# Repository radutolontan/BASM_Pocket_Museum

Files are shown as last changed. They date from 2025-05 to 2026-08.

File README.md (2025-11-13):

# Introduction

The Pocket Lab is the next-generation approach to science education. Designed by the Bucharest Applied STEAM Museum, it brings scientific exploration into anyone's hands. From citizen science projects to fearless exploration (guided or individual), the Pocket Lab illuminates the connections between Science, Technology, Engineering, Art, and Math in the world around us.

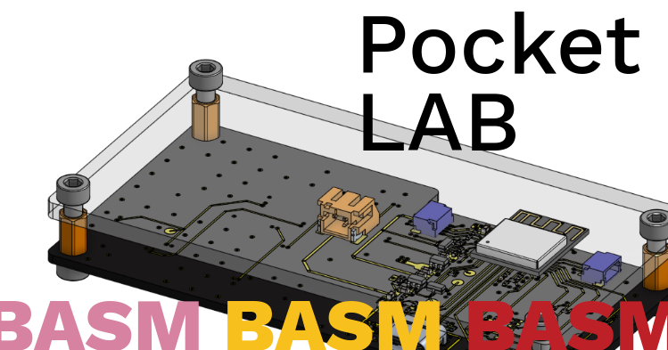
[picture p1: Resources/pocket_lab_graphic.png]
Graphic


---

# Hardware Design

The system is built around an **ESP32-C6 MINI** microcontroller, which offers:
- Powerful processing capabilities
- WiFi and Bluetooth connectivity
- Excellent integration with accessible codebases through Arduino

The microcontroller collects data from a suite of sensors (9-DOF IMU, light, pressure, audio) and uses a chain of WS2812B RGB LEDs to relay measurements to the user. An on-board microSD card enables data logging and automated grading of student work. Everything is powered by a 3.7V LiPo cell, which is charged using the USB-C connector.
## Board ID - Education V0
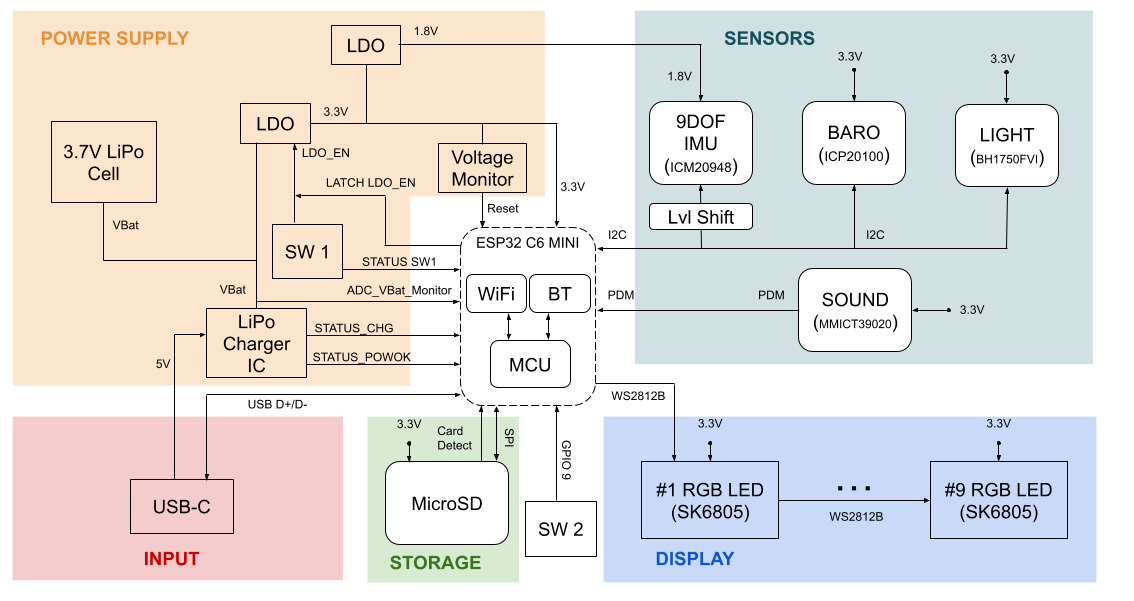
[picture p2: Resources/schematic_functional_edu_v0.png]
diagram_HW


### Power
The power stage is designed for a **500 mAh, 3.7V LiPo cell**. Key specifications:
- **Charger IC**: Configured to supply 450 mA in constant-current regime; stops charging when current drops below 150 mA in constant-voltage regime
- **USB-C Power**: Non-negotiated supply limited to 5V @ 500 mA (sufficient for system operation)
- **Voltage Monitor**: Prevents brown-out behavior on the ESP32 when the 3.3V rail drops below 2.9V
- **Power Latching**: A simple circuit enables and latches the LDO through push-button SW1 and an ESP32 GPIO 

### Display
The display consists of a chain of NeoPixel RGB LEDs organized across three zones:

**Mode Display (2 LEDs)** - Color-coded indication of the actively displayed quantity:
- WHITE → Light
- MAGENTA → Sound
- YELLOW → Magnetic Field
- GREEN → Acceleration
- ORANGE → Gyroscope
- RED → Air Temperature
- BLUE → Air Pressure

Additional device information is also displayed (e.g., battery state: Blinking Orange = Battery Low; Blinking Green = Charging; Blinking Blue = Fully Charged)

**Magnitude Display (3-4 LEDs)** - Conveys scalar quantities and magnitudes of vector quantities

**Direction Display (3 LEDs)** - Conveys qualitative Cartesian components (X, Y, Z) for vector quantities
- *Note: Direction Display is only available in Binary Display Mode (see Software Architecture section)*

### Sensors
The Pocket Lab EDU V0 includes the following sensors:

| Sensor | Measurements |
|---|---|
| **ICM-20948** | 9-DOF IMU: translational acceleration, rotational velocity, magnetic field strength |
| **ICP-20100** | Ambient temperature and air pressure |
| **BH1750FVI** | Ambient light intensity |
| **MMICT390200012** | Microphone: sound pressure level (dB) |

### Programming
The MCU can be programmed through **Joint Download Boot Mode**:

1. Connect the Pocket Lab to a host computer using a USB-C data cable
2. Hold down **SW2** (labeled "MOD"; connected to GPIO 9)
3. While holding SW2, press and hold **SW1** (labeled "ON/OFF")
4. Release SW2 while keeping SW1 pressed
5. Release SW1

The USB-serial connection appears as `/dev/ttyACM*` (Linux) and allows PlatformIO to flash code to the ESP32-C6.

# Software Architecture

The software architecture is built around a FreeRTOS task-based design with a central `shared_data_buffer` for inter-task communication. Tasks are organized into two tiers:

## Task Organization

### First-Tier Tasks (Core System)
These tasks are **always active** and form the foundation of the Pocket Lab operation:
- **BMSTask** - Battery management and power control
- **SensorTask** - Sensor data acquisition and processing
- **AudioTask** - Audio input/output management
- **DisplayTask** - User interface via NeoPixel LEDs

### Application-Level Tasks (Feature-Specific)
These tasks are **conditionally enabled** based on active applications, demos, or features:
- **SDManager** - MicroSD card operations for data logging
- **EvaluatorTask** - Student performance assessment and grading
- **NetworkTask** - WiFi/Bluetooth connectivity features

## System Architecture Diagram

```mermaid
graph TB
    subgraph "First-Tier Tasks"
        BMS[BMSTask<br/>Power Management]
        SENSOR[SensorTask<br/>Data Acquisition]
        AUDIO[AudioTask<br/>Audio I/O]
        DISPLAY[DisplayTask<br/>Visual Feedback]
    end

    subgraph "Shared Memory"
        BUFFER[(SharedBuffer<br/>Circular Buffer)]
    end

    subgraph "Application Tasks"
        SD[SDManager]
        EVAL[EvaluatorTask]
        NET[NetworkTask]
    end

    BMS -->|Power Status| BUFFER
    SENSOR -->|Sensor Data| BUFFER
    AUDIO -->|Audio Data| BUFFER

    BUFFER -->|Latest Data| DISPLAY
    BUFFER -->|Historical Data| SD
    BUFFER -->|Statistics| EVAL
    BUFFER -->|Stream Data| NET

    BMS -.->|Shutdown Signal| SENSOR
    BMS -.->|Shutdown Signal| AUDIO
    BMS -.->|Shutdown Signal| DISPLAY

    DISPLAY -->|Mode Changes| BUFFER

    style BMS fill:#ffcccc
    style SENSOR fill:#ccffcc
    style AUDIO fill:#ccccff
    style DISPLAY fill:#ffffcc
    style BUFFER fill:#ffccff
```

## Detailed Task Descriptions
### 1. SensorTask
Responsible for initializing, managing, collecting, and processing sensor data. Pushes each new raw reading to the `shared_data_buffer`. Uses the **SensorHAL** virtual layer, as implemented in `specific_sensor_HAL`, to standardize high-level I/O across all sensors.

Furthermore, note that different sensors are sampled at different rates based on their response characteristics and application requirements.
The task maintains individual timers for each sensor and only reads when that sensor's interval has elapsed, optimizing power consumption and computational load.

#### States
* **BOOT** - Default state on boot-up; transition to INIT triggered from main.cpp
* **INIT** - Initializes I2C bus for communications to sensors, configures and confirms communications with all sensors
* **READ** - If a sensor is ready to read (based on its individual `read_rate_Hz`), captures a raw reading and commits it to the latest frame of `shared_data_buffer`

### 2. BMSTask
Responsible for managing power delivery to the Pocket Lab. Monitors battery health, informs user about remaining run-time, and handles power-up and shut-down of the entire system.

#### States
* **BOOT** - Waits until startup timer expires. Prevents accidental power-up if SW 1 is bumped.
* **STARTUP_LATCH** - Configures Charger IC monitoring pins after confirming power is latched.
* **ACTIVE** - Monitors feedback from the Charger IC & Battery Voltage predictions to infer ChargeControllerState:
    * **BATTERY_ONLY** - Charger unplugged & battery supplying power
    * **LOW_BATTERY** - Charger unplugged & battery supplying power & less than 30 minutes of battery life remaining
    * **CHARGING** - Charger connected & battery charging
    * **DONE_CHARGING** - Charger connected & supplying power to system (battery charging complete)
* **SHUTDOWN_PENDING** - When SW 1 is pressed to initiate a shut-down, the LDO is un-latched and other tasks are informed to facilitate a clean shut-down.

#### ⚠️ Known Critical Issues
The current BMSTask implementation has several critical issues that will be addressed in future revisions:
- **Limited voltage monitoring**: VBat is only checked when in `BATTERY_ONLY` state, missing voltage drops during charging or when connected to USB
- **No automatic low-voltage disconnect**: The system does not automatically disconnect power when VBat drops dangerously low, risking deep discharge that could trigger the battery's undervoltage lockout protection

### 3. AudioTask
Manages audio input and output operations for the Pocket Lab. The AudioTask is responsible for interfacing with the microphone sensor (MMICT390200012) and any future audio peripherals through a Hardware Abstraction Layer (HAL).
This decouples high-level audio processing from hardware-specific implementations, allowing to scale audio I/O in the future.
Like the SensorTask, the AudioTask writes processed audio data (e.g., sound pressure level in dB, frequency analysis) to the `shared_data_buffer`.

#### States
* **BOOT** - Default state on boot-up; transition to INIT triggered from main.cpp
* **INIT** - Initializes audio peripherals through the AudioHAL, configures sampling parameters
* **SAMPLING** - Actively captures audio data at the configured sample rate, processes it, and commits results to `shared_data_buffer`
* **IDLE** - Audio acquisition paused (e.g., during low-power modes or when no audio display is active)

### 4. DisplayTask
Manages the primary user feedback tool, the chain of NeoPixels. A push-button (SW 2 - display mode button) is debounced and used to cycle through DisplayStates. The current DisplayState is color-coded into the **Mode Display**.

#### States
* **BOOT** - Default state on boot-up; transition to INIT triggered from main.cpp
* **INIT** - Initializes the RGB LED strip and displays a color code for the GIT SHA (used to confirm proper code version is running)
* **DISPLAY_XX** - Pulls the latest value for the XX quantity from `shared_data_buffer`. Updates the **Magnitude Display** and **Mode Display** to reflect the measurement.

The DisplayTask supports two distinct visualization modes selected at boot time by holding (or not holding) the display mode button:

#### Visualization Modes - VU

VU mode provides a classic "volume unit" meter visualization reminiscent of analog audio equipment. In this mode, scalar measurements are displayed as a horizontal bar graph using 6 magnitude LEDs. The display shows the normalized percentage of the measurement relative to predefined min/max thresholds for each sensor type.

The magnitude LEDs use a gradient color scheme that transitions smoothly from green (low values) through yellow (mid-range) to red (high values), providing an intuitive visual indication of intensity. The more LEDs that are lit, the closer the measurement is to its maximum threshold. Vector quantities in VU mode display only their magnitude - no directional information is shown.

#### Visualization Modes - Binary (Integer Encoding)

Binary mode takes a fundamentally different approach by encoding the actual integer value of measurements rather than showing a percentage. This mode provides precise numerical information that can be decoded by reading the LED colors, making it particularly useful for debugging and data verification.

The system uses 4 magnitude LEDs to encode 12-bit values (0-4095) using a novel 3-bit-per-LED color encoding scheme:

**How Binary Encoding Works:**

Each RGB LED encodes 3 bits of information using its individual color channels:
- Blue channel = Bit m (LSB for that LED)
- Yellow channel = Bit m+1 (middle bit)
- Red channel = Bit m+2 (MSB for that LED)

The LEDs are arranged from left to right, with LED #1 (leftmost) showing bits 0-2, LED #2 showing bits 3-5, LED #3 showing bits 6-8, and LED #4 (rightmost) showing bits 9-11. This arrangement means that more LEDs being lit indicates a larger magnitude.

**Color Combinations:** The 3 bits per LED create 8 possible states (0-7), each displayed as a distinct color:
- `000` → OFF
- `001` → BLUE (bit 0 only)
- `010` → YELLOW (bit 1 only)
- `011` → GREEN (bits 0+1: blue+yellow = green)
- `100` → RED (bit 2 only)
- `101` → PURPLE (bits 0+2: blue+red = purple)
- `110` → ORANGE (bits 1+2: yellow+red = orange)
- `111` → WHITE (all three bits active)

**Example:** To encode the value 1059:
- 1059 in binary = `0100 0010 0011` = 2⁰ + 2¹ + 2⁵ + 2¹⁰
- LED #1 (bits 0-2 = `011`): Blue + Yellow = **GREEN**
- LED #2 (bits 3-5 = `100`): Red only = **RED**
- LED #3 (bits 6-8 = `000`): All off = **OFF**
- LED #4 (bits 9-11 = `100`): Red only = **RED**

Before encoding, sensor readings are multiplied by sensor-specific scaling factors (defined as `BINARY_MAG_ORDER_*` constants) to convert floating-point measurements into integer values. For example, temperature is multiplied by 10, so 25.3°C becomes 253, while pressure is multiplied by 10, converting 101.32 kPa to 1013 (then clamped to 4095). Note that acceleration and gyro measurements are very noisy and flicker significantly; the first two bits are masked, effectively rounding every measurement to a multiple of 4.

**Direction Display:**

Binary mode also displays vector components (X, Y, Z) using 3 dedicated direction LEDs. Each LED shows its component using a color gradient:
- **RED** → Negative values
- **OFF** → Near-zero values (±5% dead zone)
- **GREEN** → Positive values

The intensity of the color fades proportionally with the component's magnitude, providing both sign and strength information. 

## Application-Level Task Details

### 5. EvaluatorTask
Responsible for gauging user effort and measuring learning outcomes. The EvaluatorTask owns multiple instances of the abstract base class `EvaluatorBase`.

`EvaluatorBase` standardizes I/O across all evaluators, such as `DisplaySessionEvaluator` (which captures aggregate statistics on sensor data while a specific DisplayTask mode is active). This enables automated grading and feedback for educational activities.

#### States
* **BOOT** - Default state on boot-up; transition to INIT triggered from main.cpp
* **INIT** - Initializes and confirms appropriate logging is set up for all evaluators
* **RUNNING** - Checks progress on all evaluators and manages access to the SDManager queue for data logging
* **ERROR** - Error handling (not yet implemented)

### 6. SDManager
Owns operation of the microSD card. It manages access to the storage resource using a separate state machine, handling concurrent read/write requests from multiple tasks.

#### States
* **BOOT** - Default state on boot-up; transitions to INIT automatically after initializing SD queue
* **WAIT_FOR_INSERT** - Checks and debounces the state of the SD card detect GPIO
* **MOUNTING** - Starts SPI communications, mounts the SD card, and checks SD card metadata
* **READY** - Allows fulfillment of read/write requests in the queue
* **UNMOUNTING** - Unmounts the SD card if removal is detected
* **ERROR** - Error handling (not yet implemented)

### 7. NetworkTask
Manages WiFi and Bluetooth connectivity features. This task is enabled when network-based applications are active (e.g., data streaming, remote monitoring, firmware updates).

*Note: Full NetworkTask implementation details are under development.*

---

# SD Card Formatting

In order to read and write to the SD card, it must be formatted to **FAT32** with an **MBR** partition table.

## Formatting Instructions (Linux)

1. Insert the microSD card into a compatible card reader, connect to a Linux machine, and locate the device:
```bash
lsblk
```

2. Unmount any existing partitions and clear the card (replace `/dev/sdX` with your device):
```bash
sudo umount /dev/sdX*
sudo wipefs --all /dev/sdX
sudo fdisk /dev/sdX
```

3. Within `fdisk`, configure the following:
   - Press **`o`** → Create a new DOS (MBR) partition table
   - Press **`n`** → Create a new primary partition
   - Accept all defaults (press Enter)
   - Press **`t`**, then type **`c`** → Change partition type to W95 FAT32 (LBA)
   - Press **`w`** → Write changes and exit

4. Format the partition to FAT32:
```bash
sudo mkfs.vfat -F 32 -n SDCARD /dev/sdX1
```

The SD card is now ready for use with the Pocket Lab.

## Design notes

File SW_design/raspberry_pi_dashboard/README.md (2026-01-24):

# BASM Pocket Museum Dashboard

A web-based dashboard for the Raspberry Pi that receives sensor data from ESP32 "Pocket Lab" devices and provides real-time visualization, student notebooks, and user management.

## Features

### 1. Welcome Tab
- First-time user registration (name, grade, science interest)
- Returning user greeting ("Welcome back, [Name]!")
- MAC address-based identification (hashed for privacy)

### 2. Pocket Lab Data Tab
- Real-time display of active ESP32 devices
- Interactive sensor selection (checkboxes for each sensor)
- Flexible display modes: stripchart, numeric, both, or none
- Supports all sensors:
  - Temperature & Pressure
  - Ambient Light
  - Accelerometer (X, Y, Z, Norm)
  - Gyroscope (X, Y, Z, Norm)
  - Magnetometer (X, Y, Z, Norm)
  - Volume (RMS)
  - Spectral sensor (14 channels)

### 3. Pocket Lab Notebook Tab
- Teacher-published questions (multiple choice or free text)
- Student answer submission (one answer per question)
- Answer history tracking

## Architecture

- **Backend**: Python Flask + Flask-SocketIO
- **Database**: SQLite (lightweight, perfect for Raspberry Pi)
- **Communication**: UDP (port 5000) for ESP32 data, WebSocket for real-time browser updates
- **Frontend**: HTML/CSS/JavaScript (will be implemented next)

## Installation

### Prerequisites

- Raspberry Pi 4 (2GB+ RAM recommended)
- Raspberry Pi OS (Debian-based)
- Python 3.9+
- Static IP configured: 192.168.10.2

### Step 1: Clone Repository

```bash
cd /home/pi/
git clone <repository-url> BASM_Pocket_Museum
cd BASM_Pocket_Museum/SW_design/raspberry_pi_dashboard
```

### Step 2: Install Dependencies

```bash
pip3 install -r requirements.txt
```

### Step 3: Configure Environment

```bash
cp .env.example .env
nano .env
```

Edit `.env` to customize settings (or use defaults):

```env
FLASK_ENV=production
SECRET_KEY=<generate-random-secret-key>
UDP_PORT=5000
WEB_PORT=8080
ACTIVITY_TIMEOUT_SECONDS=5
SENSOR_DATA_RETENTION_HOURS=24
```

### Step 4: Initialize Database

```bash
python3 init_db.py
```

You should see:
```
✓ Database initialized successfully!
✓ Schema version 1 applied
```

### Step 5: Run the Application

For development:
```bash
python3 app.py
```

For production (systemd service):
```bash
sudo cp dashboard.service /etc/systemd/system/
sudo systemctl daemon-reload
sudo systemctl enable dashboard
sudo systemctl start dashboard
```

Check status:
```bash
sudo systemctl status dashboard
```

View logs:
```bash
sudo journalctl -u dashboard -f
```

## Configuration

### Network Setup

The Raspberry Pi must have a static IP address that matches the ESP32 configuration:

**Raspberry Pi**: 192.168.10.2
**ESP32 Devices**: 192.168.10.11, 192.168.10.12, etc.

Edit `/etc/dhcpcd.conf`:
```
interface eth0
static ip_address=192.168.10.2/24
static routers=192.168.10.1
static domain_name_servers=8.8.8.8
```

Restart networking:
```bash
sudo systemctl restart dhcpcd
```

### Firewall

Allow incoming UDP on port 5000 and HTTP on port 8080:

```bash
sudo ufw allow 5000/udp
sudo ufw allow 8080/tcp
```

## API Documentation

### REST API Endpoints

#### Users

**Register/Login User**
```http
POST /api/users/register
Content-Type: application/json

{
  "mac_address": "AA:BB:CC:DD:EE:FF",
  "name": "John Doe",
  "grade": "10th",
  "science_interest": "Physics and robotics"
}
```

**Get User**
```http
GET /api/users/<mac_id>
```

#### Devices

**Get Active Devices**
```http
GET /api/devices
```

**Get Specific Device**
```http
GET /api/devices/<node_id>
```

#### Sensor Data

**Get Sensor Data**
```http
GET /api/sensor-data/<node_id>?limit=1000&hours=1&sensors=temperature,pressure
```

Parameters:
- `limit`: Max records (default: 1000)
- `hours`: Data from last N hours (default: 1)
- `sensors`: Comma-separated sensor list (optional)

#### Questions

**Get Active Questions**
```http
GET /api/questions
```

**Create Question (Teacher)**
```http
POST /api/questions
Content-Type: application/json

{
  "question_text": "What is the acceleration due to gravity?",
  "question_type": "multiple_choice",
  "options": ["9.8 m/s²", "10 m/s²", "8.9 m/s²", "11.2 m/s²"],
  "created_by": "Mrs. Smith"
}
```

**Delete Question**
```http
DELETE /api/questions/<question_id>
```

#### Answers

**Submit Answer**
```http
POST /api/answers
Content-Type: application/json

{
  "question_id": 1,
  "mac_id": "<hashed_mac_id>",
  "answer": "9.8 m/s²"
}
```

**Get User Answers**
```http
GET /api/answers/user/<mac_id>
```

**Get Question Answers (Teacher)**
```http
GET /api/answers/question/<question_id>
```

#### Preferences

**Get Preferences**
```http
GET /api/preferences?mac_id=<mac_id>&node_id=<node_id>
```

**Save Preferences**
```http
POST /api/preferences
Content-Type: application/json

{
  "mac_id": "<mac_id>",
  "node_id": "LAB_01",
  "sensor_type": "temperature",
  "display_type": "both"
}
```

Display types: `stripchart`, `numeric`, `both`, `none`

### WebSocket Events

**Connect**
```javascript
const socket = io('http://192.168.10.2:8080');
```

**Subscribe to Device**
```javascript
socket.emit('subscribe_device', {node_id: 'LAB_01'});
```

**Receive Sensor Data**
```javascript
socket.on('sensor_data', (data) => {
  console.log(data.node_id, data.data);
});
```

**Receive New Question**
```javascript
socket.on('new_question', (question) => {
  console.log('New question:', question);
});
```

## Maintenance

### Automatic Cleanup

Add to crontab for hourly cleanup:

```bash
crontab -e
```

Add line:
```
0 * * * * /usr/bin/python3 /home/pi/BASM_Pocket_Museum/raspberry_pi_dashboard/cleanup_sensor_data.py >> /var/log/basm-cleanup.log 2>&1
```

### Manual Cleanup

```bash
python3 cleanup_sensor_data.py
```

### Database Backup

```bash
# Create backup
cp dashboard.db dashboard_backup_$(date +%Y%m%d).db

# Or use SQLite backup command
sqlite3 dashboard.db ".backup /path/to/backup.db"
```

### View Database

```bash
sqlite3 dashboard.db

# Useful queries
SELECT COUNT(*) FROM sensor_data;
SELECT node_id, MAX(timestamp) FROM sensor_data GROUP BY node_id;
SELECT * FROM users;
```

## Troubleshooting

### No ESP32 Data Received

1. Check ESP32 is transmitting:
```bash
# Listen on UDP port 5000
nc -ul 5000
```

2. Check firewall:
```bash
sudo ufw status
```

3. Check dashboard logs:
```bash
sudo journalctl -u dashboard -f
```

### Database Errors

1. Check permissions:
```bash
ls -la dashboard.db
# Should be writable by the user running the service
```

2. Re-initialize:
```bash
rm dashboard.db
python3 init_db.py
```

### High CPU/Memory Usage

1. Check sensor data table size:
```bash
sqlite3 dashboard.db "SELECT COUNT(*) FROM sensor_data;"
```

2. Run cleanup:
```bash
python3 cleanup_sensor_data.py
```

3. Reduce retention hours in `.env`:
```env
SENSOR_DATA_RETENTION_HOURS=12
```

## Development

### Run in Development Mode

```bash
export FLASK_ENV=development
export FLASK_DEBUG=True
python3 app.py
```

### Testing

```bash
# Test UDP listener
python3 -c "import socket, json; s = socket.socket(socket.AF_INET, socket.SOCK_DGRAM); s.sendto(json.dumps({'node_id': 'LAB_TEST', 'temperature': 23.5}).encode(), ('127.0.0.1', 5000))"

# Test REST API
curl http://localhost:8080/api/devices

# Test WebSocket
# Use browser console or tool like wscat
```

## Next Steps

- [ ] Implement frontend UI (HTML/CSS/JavaScript)
- [ ] Add authentication for teacher admin panel
- [ ] Implement data export (CSV/Excel)
- [ ] Add advanced visualizations (spectral charts)
- [ ] Mobile responsive design

## License

[Your License Here]

## Contact

[Your Contact Information]

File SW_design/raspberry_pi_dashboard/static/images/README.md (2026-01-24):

# Pocket Lab Icon

## Required Image

Please place your Pocket Lab icon PNG image in this directory with the filename:

**`pocket-lab-icon.png`**

## Specifications

- **Format**: PNG with transparency (recommended)
- **Size**: Any size (will be displayed at 64x64 pixels)
- **Aspect ratio**: Square is recommended but not required
- **Usage**: This icon appears on device selection cards for each Pocket Lab

## Current Path

The dashboard looks for the image at:
```
/images/pocket-lab-icon.png
```

Which corresponds to:
```
raspberry_pi_dashboard/static/images/pocket-lab-icon.png
```

## If Image is Missing

If the image file is not found, browsers will show a broken image icon. To use the default Bootstrap icon instead, you can modify line 444 in `static/js/pocket-lab-live.js`:

```javascript
// Current (custom PNG):
<img src="/images/pocket-lab-icon.png" alt="Pocket Lab" style="width: 64px; height: 64px; object-fit: contain;" />

// Alternative (Bootstrap icon):
<i class="bi bi-cpu-fill"></i>
```

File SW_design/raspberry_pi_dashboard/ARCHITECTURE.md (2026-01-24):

# Raspberry Pi Dashboard Architecture

## System Overview

The Raspberry Pi Dashboard is a web-based interface for managing and visualizing data from multiple ESP32 "Pocket Lab" devices. The system provides real-time sensor monitoring, student notebooks, and user management.

## Technology Stack

### Backend
- **Python 3.9+**: Main programming language
- **Flask**: Web framework for REST API and web server
- **Flask-SocketIO**: WebSocket support for real-time data streaming
- **SQLite**: Lightweight database (ideal for Raspberry Pi)
- **SQLAlchemy**: ORM for database operations
- **Threading**: UDP listener runs in separate thread

### Frontend
- **HTML5/CSS3/JavaScript**: Core web technologies
- **Bootstrap 5**: Responsive UI framework
- **Chart.js**: Real-time strip charts and visualizations
- **Socket.IO Client**: WebSocket client for real-time updates
- **Fetch API**: REST API calls

### Communication
- **UDP Server (Port 5000)**: Receives JSON packets from ESP32 devices
- **WebSocket (Socket.IO)**: Real-time data push to browser clients
- **REST API**: User management, device control, questions/answers
- **HTTP/HTTPS**: Web server (default port 8080)

## System Architecture

```
┌─────────────────────────────────────────────────────────────────┐
│                          ESP32 Devices                          │
│  (LAB_01, LAB_02, ... LAB_N) @ 25-50 Hz each                   │
│  Send JSON over UDP to 192.168.10.2:5000                       │
└────────────────────────┬────────────────────────────────────────┘
                         │ UDP JSON packets
                         ▼
┌─────────────────────────────────────────────────────────────────┐
│                    Raspberry Pi Server                          │
│  ┌──────────────────────────────────────────────────────────┐  │
│  │  UDP Listener Thread (Port 5000)                         │  │
│  │  - Receives JSON packets from ESP32 devices              │  │
│  │  - Parses sensor data                                    │  │
│  │  - Updates device activity status                        │  │
│  │  - Writes to database (sensor_data, devices)             │  │
│  │  - Broadcasts to WebSocket clients                       │  │
│  └─────────────┬────────────────────────────────────────────┘  │
│                │                                                │
│  ┌─────────────▼────────────────────────────────────────────┐  │
│  │  Flask Web Server (Port 8080)                            │  │
│  │  ┌────────────────────────────────────────────────────┐  │  │
│  │  │  REST API Endpoints                                │  │  │
│  │  │  - /api/users (MAC ID management)                  │  │  │
│  │  │  - /api/devices (list active ESP32 devices)        │  │  │
│  │  │  - /api/sensor-data/:node_id (historical data)     │  │  │
│  │  │  - /api/preferences (user sensor preferences)      │  │  │
│  │  │  - /api/questions (teacher question management)    │  │  │
│  │  │  - /api/answers (student answers)                  │  │  │
│  │  └────────────────────────────────────────────────────┘  │  │
│  │  ┌────────────────────────────────────────────────────┐  │  │
│  │  │  WebSocket (Socket.IO)                             │  │  │
│  │  │  - Real-time sensor data broadcast                 │  │  │
│  │  │  - Device status updates                           │  │  │
│  │  │  - Question notifications                          │  │  │
│  │  └────────────────────────────────────────────────────┘  │  │
│  │  ┌────────────────────────────────────────────────────┐  │  │
│  │  │  Static File Server                                │  │  │
│  │  │  - Serves HTML/CSS/JS frontend                     │  │  │
│  │  └────────────────────────────────────────────────────┘  │  │
│  └──────────────────────────────────────────────────────────┘  │
│                                                                 │
│  ┌──────────────────────────────────────────────────────────┐  │
│  │  SQLite Database (dashboard.db)                          │  │
│  │  - users (MAC ID registration)                           │  │
│  │  - devices (ESP32 tracking)                              │  │
│  │  - sensor_data (time-series data)                        │  │
│  │  - questions (teacher questions)                         │  │
│  │  - answers (student responses)                           │  │
│  │  - user_preferences (sensor display settings)            │  │
│  └──────────────────────────────────────────────────────────┘  │
└────────────────────────┬────────────────────────────────────────┘
                         │ WebSocket + HTTP
                         ▼
┌─────────────────────────────────────────────────────────────────┐
│                      Browser Clients                            │
│  ┌──────────────────────────────────────────────────────────┐  │
│  │  Frontend Application (SPA)                              │  │
│  │  ┌────────────────┐ ┌────────────────┐ ┌──────────────┐ │  │
│  │  │  Welcome Tab   │ │ Pocket Lab     │ │  Notebook    │ │  │
│  │  │  - MAC ID reg  │ │ Data Tab       │ │  Tab         │ │  │
│  │  │  - User greet  │ │ - Device list  │ │  - Questions │ │  │
│  │  │                │ │ - Sensor cards │ │  - Answers   │ │  │
│  │  │                │ │ - Strip charts │ │              │ │  │
│  │  └────────────────┘ └────────────────┘ └──────────────┘ │  │
│  └──────────────────────────────────────────────────────────┘  │
└─────────────────────────────────────────────────────────────────┘
```

## Data Flow

### 1. ESP32 → Raspberry Pi (Sensor Data Ingestion)
```
ESP32 Device
  ↓ (UDP JSON @ 25-50 Hz)
UDP Listener (Port 5000)
  ↓ Parse JSON
  ↓ Extract node_id, sensor values
  ↓ Update device last_seen timestamp
  ↓ Store in database (sensor_data table)
  ↓ Broadcast via WebSocket
Browser Clients (real-time update)
```

### 2. Browser → Raspberry Pi (User Registration)
```
Browser (Welcome Tab)
  ↓ POST /api/users/register
  ↓ {mac_id, name, grade, science_interest}
Flask API
  ↓ Check if user exists
  ↓ Create new user or return existing
  ↓ Store in database (users table)
  ↓ Return user profile
Browser (display welcome message)
```

### 3. Browser → Raspberry Pi (Device & Sensor Selection)
```
Browser (Pocket Lab Data Tab)
  ↓ GET /api/devices (fetch active devices)
Flask API
  ↓ Query devices with last_seen > (now - timeout)
  ↓ Return list of active devices
Browser (display device rectangles)
  ↓ User clicks device
  ↓ User selects sensors & display types
  ↓ POST /api/preferences
  ↓ {mac_id, node_id, sensor_type, display_type}
Flask API
  ↓ Store preferences in database
  ↓ Return success
Browser
  ↓ Subscribe to WebSocket for selected node
  ↓ GET /api/sensor-data/:node_id (historical data)
  ↓ Render strip charts / numeric displays
  ↓ Receive real-time updates via WebSocket
```

### 4. Browser → Raspberry Pi (Notebook Questions/Answers)
```
Teacher:
  Browser (admin interface)
    ↓ POST /api/questions
    ↓ {question_text, question_type, options}
  Flask API
    ↓ Store in database (questions table)
    ↓ Broadcast new question notification
  All browsers (receive notification)

Student:
  Browser (Notebook Tab)
    ↓ GET /api/questions (fetch active questions)
    ↓ Display questions
    ↓ User submits answer
    ↓ POST /api/answers
    ↓ {mac_id, question_id, answer}
  Flask API
    ↓ Check if already answered (UNIQUE constraint)
    ↓ Store in database (answers table)
    ↓ Return success or error
```

## Key Components

### 1. UDP Listener (`udp_listener.py`)
- Runs in separate thread
- Listens on port 5000
- Parses incoming JSON packets
- Updates device activity
- Stores sensor data
- Broadcasts to WebSocket clients
- Handles multiple ESP32 devices concurrently

### 2. Flask Application (`app.py`)
- Main web server
- REST API endpoints
- WebSocket server (Socket.IO)
- Static file serving
- Database initialization
- CORS configuration

### 3. Database Models (`models.py`)
- User (MAC ID, name, grade, science_interest)
- Device (node_id, hostname, last_seen, is_active)
- SensorData (time-series sensor readings)
- Question (teacher questions)
- Answer (student responses)
- UserPreference (sensor display preferences)

### 4. Frontend (`static/` directory)
- `index.html`: Main application shell
- `css/styles.css`: Styling
- `js/app.js`: Main application logic
- `js/welcome.js`: Welcome tab
- `js/data-tab.js`: Pocket Lab Data tab
- `js/notebook.js`: Notebook tab
- `js/charts.js`: Chart.js utilities
- `js/websocket.js`: Socket.IO client

## Device Activity Tracking

### Timeout Logic
- Devices are considered **ACTIVE** if `last_seen > (now - ACTIVITY_TIMEOUT)`
- Default timeout: **5 seconds** (configurable)
- UDP Listener updates `last_seen` on every packet
- Frontend polls `/api/devices` every 2 seconds
- Inactive devices are hidden from the UI

### Hostname Resolution
- ESP32 sends `node_id` in JSON (e.g., "LAB_01")
- Hostname (e.g., "ESP32-01") can be inferred from node_id or stored separately
- Database stores both `node_id` (unique identifier) and `hostname` (display name)

## Security Considerations

### MAC Address Privacy
- MAC addresses are hashed with SHA-256 before storage
- Hash is used as user identifier
- Original MAC address not stored in database
- Frontend sends hash, not raw MAC address

### Authentication (Future Enhancement)
- Current version: Open access (suitable for classroom)
- Future: Teacher admin panel with password protection
- Future: Student login with PIN or QR code

### Data Retention
- Sensor data older than 24 hours automatically pruned
- Configurable retention policy
- Questions can be archived (soft delete)

## Configuration

### Environment Variables (`.env` file)
```
FLASK_ENV=production
FLASK_DEBUG=False
DATABASE_URL=sqlite:///dashboard.db
UDP_PORT=5000
WEB_PORT=8080
ACTIVITY_TIMEOUT=5
SENSOR_DATA_RETENTION_HOURS=24
SECRET_KEY=<random-secret-key>
```

## Deployment on Raspberry Pi

### System Requirements
- Raspberry Pi 4 (2GB+ RAM recommended)
- Raspberry Pi OS (Debian-based)
- Python 3.9+
- 10GB+ available storage

### Installation Steps
```bash
# Clone repository
cd /home/pi/
git clone <repository-url> BASM_Dashboard

# Install dependencies
cd BASM_Dashboard/raspberry_pi_dashboard
pip3 install -r requirements.txt

# Initialize database
python3 init_db.py

# Run application
python3 app.py
```

### Systemd Service (Auto-start on boot)
```bash
sudo cp dashboard.service /etc/systemd/system/
sudo systemctl enable dashboard
sudo systemctl start dashboard
```

### Network Configuration
- Static IP: 192.168.10.2 (matches ESP32 SERVER_IP_ADDRESS)
- Subnet: 192.168.10.0/24
- Router: Configure DHCP reservations for ESP32 devices

## Performance Considerations

### Database Optimization
- Index on `node_id`, `timestamp`, `mac_id`
- Periodic VACUUM to reclaim space
- Write-ahead logging (WAL) mode for concurrent reads

### WebSocket Optimization
- Broadcast only to subscribed rooms (per-device)
- Throttle broadcast rate (max 10 Hz per sensor)
- Client-side data buffering

### Memory Management
- Limit sensor_data table size (auto-prune old data)
- Circular buffer for real-time data (in-memory)
- Connection pooling for database

## Testing Strategy

### Unit Tests
- Database models (CRUD operations)
- API endpoints (REST)
- UDP packet parsing
- WebSocket message handling

### Integration Tests
- End-to-end data flow (ESP32 → DB → Browser)
- Multi-device scenarios
- Concurrent user access

### Load Testing
- Simulate 10+ ESP32 devices @ 50 Hz each
- Measure latency, CPU, memory usage
- Identify bottlenecks

## Future Enhancements

1. **Data Export**: CSV/Excel export of sensor data
2. **Advanced Analytics**: Statistical analysis, data trends
3. **Mobile App**: Native iOS/Android app
4. **Cloud Sync**: Backup to cloud storage
5. **Multi-language Support**: Internationalization (i18n)
6. **Custom Dashboards**: User-configurable layouts
7. **Alerts & Notifications**: Threshold-based alerts
8. **Spectral Sensor Visualization**: Full spectrum charts (AS7343)
9. **Video Recording**: Sync sensor data with video timestamps
10. **Collaborative Notes**: Shared student notebooks

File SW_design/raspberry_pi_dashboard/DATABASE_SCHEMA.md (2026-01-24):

# Database Schema

## Overview

The dashboard uses **SQLite** as the database engine. SQLite is lightweight, serverless, and perfect for Raspberry Pi deployment. The schema is designed for:
- Fast reads (real-time data access)
- Efficient writes (25-50 Hz data ingestion per ESP32)
- Data integrity (foreign keys, unique constraints)
- Automatic cleanup (TTL for sensor data)

## Schema Diagram

```
┌──────────────┐
│    users     │
│──────────────│
│ mac_id (PK)  │◄────────┐
│ name         │          │
│ grade        │          │
│ science_int  │          │
│ first_seen   │          │
│ last_seen    │          │
└──────────────┘          │
                          │
┌──────────────┐          │
│   devices    │          │
│──────────────│          │
│ node_id (PK) │◄───┐     │
│ hostname     │    │     │
│ ip_address   │    │     │
│ last_seen    │    │     │
│ is_active    │    │     │
└──────────────┘    │     │
                    │     │
┌──────────────┐    │     │
│ sensor_data  │    │     │
│──────────────│    │     │
│ id (PK)      │    │     │
│ node_id (FK) │────┘     │
│ timestamp    │          │
│ temperature  │          │
│ pressure     │          │
│ light_int    │          │
│ accel_x/y/z  │          │
│ gyro_x/y/z   │          │
│ mag_x/y/z    │          │
│ volume_rms   │          │
│ ... etc      │          │
└──────────────┘          │
                          │
┌──────────────┐          │
│  questions   │          │
│──────────────│          │
│ id (PK)      │◄───┐     │
│ question_txt │    │     │
│ type         │    │     │
│ options      │    │     │
│ created_at   │    │     │
│ is_active    │    │     │
└──────────────┘    │     │
                    │     │
┌──────────────┐    │     │
│   answers    │    │     │
│──────────────│    │     │
│ id (PK)      │    │     │
│ question_id  │────┘     │
│ mac_id (FK)  │──────────┘
│ answer       │
│ answered_at  │
│ UNIQUE(q,m)  │
└──────────────┘

┌──────────────┐
│ user_prefs   │
│──────────────│
│ id (PK)      │
│ mac_id (FK)  │──────────┘
│ node_id (FK) │──────────┘
│ sensor_type  │
│ display_type │
│ created_at   │
│ updated_at   │
└──────────────┘
```

## Tables

### 1. `users` - User Registration & Profiles

Stores student/user information collected on first visit.

| Column | Type | Constraints | Description |
|---|---|---|---|
| `mac_id` | VARCHAR(64) | PRIMARY KEY | SHA-256 hash of MAC address |
| `name` | VARCHAR(100) | NOT NULL | User's name |
| `grade` | VARCHAR(20) | NULL | Grade level (e.g., "9th", "10th") |
| `science_interest` | TEXT | NULL | Interest in science (free text) |
| `first_seen` | TIMESTAMP | DEFAULT CURRENT_TIMESTAMP | First visit timestamp |
| `last_seen` | TIMESTAMP | DEFAULT CURRENT_TIMESTAMP | Most recent visit |

**Indexes:**
- PRIMARY KEY on `mac_id`
- INDEX on `last_seen` (for recent user queries)

**Example Data:**
```sql
INSERT INTO users VALUES (
  'a3f5b8c9d2e1f4g7h8i9j0k1l2m3n4o5p6q7r8s9t0u1v2w3x4y5z6a7b8c9d0e1f2',
  'Raul Popescu',
  '10th',
  'I love physics and robotics!',
  '2025-10-31 09:15:23',
  '2025-10-31 14:32:11'
);
```

---

### 2. `devices` - ESP32 Device Tracking

Tracks all ESP32 "Pocket Lab" devices that have ever connected.

| Column | Type | Constraints | Description |
|---|---|---|---|
| `node_id` | VARCHAR(50) | PRIMARY KEY | Node ID from ESP32 (e.g., "LAB_01") |
| `hostname` | VARCHAR(100) | NULL | Network hostname (e.g., "ESP32-01") |
| `ip_address` | VARCHAR(15) | NULL | Last known IP address |
| `last_seen` | TIMESTAMP | DEFAULT CURRENT_TIMESTAMP | Last data packet received |
| `is_active` | BOOLEAN | DEFAULT TRUE | Computed: last_seen > (now - timeout) |

**Indexes:**
- PRIMARY KEY on `node_id`
- INDEX on `last_seen` (for active device queries)
- INDEX on `is_active, last_seen` (composite index for active filtering)

**Example Data:**
```sql
INSERT INTO devices VALUES (
  'LAB_01',
  'ESP32-01',
  '192.168.10.11',
  '2025-10-31 14:32:15',
  TRUE
);
```

**Notes:**
- `is_active` is computed on read: `last_seen > (CURRENT_TIMESTAMP - ACTIVITY_TIMEOUT)`
- Devices are never deleted, only marked inactive
- `hostname` extracted from initial connection or inferred from `node_id`

---

### 3. `sensor_data` - Time-Series Sensor Readings

Stores all sensor data from ESP32 devices. This is the largest table.

| Column | Type | Constraints | Description |
|---|---|---|---|
| `id` | INTEGER | PRIMARY KEY AUTOINCREMENT | Unique record ID |
| `node_id` | VARCHAR(50) | FOREIGN KEY → devices(node_id) | Source device |
| `timestamp` | TIMESTAMP | NOT NULL | Server receive time |
| `esp_timestamp` | INTEGER | NULL | ESP32 millis() value |
| `temperature` | REAL | NULL | Temperature (°C) |
| `pressure` | REAL | NULL | Pressure (Pa) |
| `light_intensity` | REAL | NULL | Ambient light (lux) |
| `accel_x` | REAL | NULL | Acceleration X (mg) |
| `accel_y` | REAL | NULL | Acceleration Y (mg) |
| `accel_z` | REAL | NULL | Acceleration Z (mg) |
| `accel_norm` | REAL | NULL | Acceleration norm (mg) |
| `gyro_x` | REAL | NULL | Gyroscope X (deg/s) |
| `gyro_y` | REAL | NULL | Gyroscope Y (deg/s) |
| `gyro_z` | REAL | NULL | Gyroscope Z (deg/s) |
| `gyro_norm` | REAL | NULL | Gyroscope norm (deg/s) |
| `mag_x` | REAL | NULL | Magnetometer X (µT) |
| `mag_y` | REAL | NULL | Magnetometer Y (µT) |
| `mag_z` | REAL | NULL | Magnetometer Z (µT) |
| `mag_norm` | REAL | NULL | Magnetometer norm (µT) |
| `volume_rms` | REAL | NULL | Sound level (dB) |
| `spectral_f1_405nm` | REAL | NULL | Spectral channel F1 (405nm) |
| `spectral_f2_425nm` | REAL | NULL | Spectral channel F2 (425nm) |
| `spectral_f3_475nm` | REAL | NULL | Spectral channel F3 (475nm) |
| `spectral_f4_515nm` | REAL | NULL | Spectral channel F4 (515nm) |
| `spectral_fz_450nm` | REAL | NULL | Spectral channel FZ (450nm) |
| `spectral_fy_555nm` | REAL | NULL | Spectral channel FY (555nm) |
| `spectral_f5_550nm` | REAL | NULL | Spectral channel F5 (550nm) |
| `spectral_f6_640nm` | REAL | NULL | Spectral channel F6 (640nm) |
| `spectral_fxl_600nm` | REAL | NULL | Spectral channel FXL (600nm) |
| `spectral_f7_690nm` | REAL | NULL | Spectral channel F7 (690nm) |
| `spectral_f8_745nm` | REAL | NULL | Spectral channel F8 (745nm) |
| `spectral_nir_855nm` | REAL | NULL | Spectral channel NIR (855nm) |
| `spectral_vis` | REAL | NULL | Spectral visible light |
| `spectral_fd` | REAL | NULL | Spectral flicker detection |

**Indexes:**
- PRIMARY KEY on `id`
- INDEX on `node_id` (for per-device queries)
- INDEX on `timestamp` (for time-range queries)
- COMPOSITE INDEX on `node_id, timestamp DESC` (most common query pattern)

**Constraints:**
- FOREIGN KEY `node_id` REFERENCES `devices(node_id)` ON DELETE CASCADE
- CHECK: `timestamp >= '2025-01-01'` (prevent garbage data)

**Example Data:**
```sql
INSERT INTO sensor_data (node_id, timestamp, esp_timestamp, temperature, pressure, light_intensity, accel_x, accel_y, accel_z, accel_norm) VALUES (
  'LAB_01',
  '2025-10-31 14:32:15.123',
  123456789,
  23.45,
  101325.0,
  542.1,
  0.012,
  -0.005,
  1.003,
  1.004
);
```

**Data Retention Policy:**
- Automatic deletion of records older than `SENSOR_DATA_RETENTION_HOURS` (default: 24 hours)
- Implemented via cron job or periodic background task
- Example cleanup query:
```sql
DELETE FROM sensor_data
WHERE timestamp < datetime('now', '-24 hours');
```

**Storage Estimate:**
- ~200 bytes per record (with all sensors)
- 10 devices @ 50 Hz = 500 records/sec = 43M records/day
- 43M × 200 bytes = 8.6 GB/day (if all sensors active)
- With 24-hour retention: ~10 GB database size (worst case)
- Realistic: ~2-3 GB (sparse sensor data, lower rates)

---

### 4. `questions` - Teacher Questions for Notebook

Stores questions published by teachers for students to answer.

| Column | Type | Constraints | Description |
|---|---|---|---|
| `id` | INTEGER | PRIMARY KEY AUTOINCREMENT | Unique question ID |
| `question_text` | TEXT | NOT NULL | The question text |
| `question_type` | VARCHAR(20) | NOT NULL | 'multiple_choice' or 'free_text' |
| `options` | TEXT | NULL | JSON array of options (for multiple choice) |
| `created_at` | TIMESTAMP | DEFAULT CURRENT_TIMESTAMP | When question was published |
| `is_active` | BOOLEAN | DEFAULT TRUE | Active questions shown to students |
| `created_by` | VARCHAR(100) | NULL | Teacher name (future: teacher_id FK) |

**Indexes:**
- PRIMARY KEY on `id`
- INDEX on `is_active, created_at DESC` (for active question listing)

**Example Data:**

Multiple Choice:
```sql
INSERT INTO questions (question_text, question_type, options) VALUES (
  'What is the acceleration due to gravity on Earth?',
  'multiple_choice',
  '["9.8 m/s²", "10 m/s²", "8.9 m/s²", "11.2 m/s²"]'
);
```

Free Text:
```sql
INSERT INTO questions (question_text, question_type) VALUES (
  'Describe what happens to air pressure as you increase altitude.',
  'free_text',
  NULL
);
```

**Notes:**
- `options` is stored as JSON string
- Only shown to students if `is_active = TRUE`
- Teachers can archive questions (set `is_active = FALSE`)

---

### 5. `answers` - Student Answers to Questions

Stores student responses to questions. Students can only answer each question once.

| Column | Type | Constraints | Description |
|---|---|---|---|
| `id` | INTEGER | PRIMARY KEY AUTOINCREMENT | Unique answer ID |
| `question_id` | INTEGER | FOREIGN KEY → questions(id) | Which question |
| `mac_id` | VARCHAR(64) | FOREIGN KEY → users(mac_id) | Which student |
| `answer` | TEXT | NOT NULL | Student's answer |
| `answered_at` | TIMESTAMP | DEFAULT CURRENT_TIMESTAMP | When answered |

**Indexes:**
- PRIMARY KEY on `id`
- UNIQUE INDEX on `(question_id, mac_id)` (prevent duplicate answers)
- INDEX on `question_id` (for per-question answer listing)
- INDEX on `mac_id` (for per-student answer history)

**Constraints:**
- FOREIGN KEY `question_id` REFERENCES `questions(id)` ON DELETE CASCADE
- FOREIGN KEY `mac_id` REFERENCES `users(mac_id)` ON DELETE CASCADE
- UNIQUE (`question_id`, `mac_id`) - prevents answering same question twice

**Example Data:**
```sql
INSERT INTO answers (question_id, mac_id, answer) VALUES (
  1,
  'a3f5b8c9d2e1f4g7h8i9j0k1l2m3n4o5p6q7r8s9t0u1v2w3x4y5z6a7b8c9d0e1f2',
  '9.8 m/s²',
  '2025-10-31 14:35:22'
);
```

**Error Handling:**
- If student tries to answer same question twice → return 409 Conflict
- Frontend disables "Submit" button for already-answered questions

---

### 6. `user_preferences` - Sensor Display Preferences

Stores user preferences for which sensors to display and how (stripchart, numeric, both, none).

| Column | Type | Constraints | Description |
|---|---|---|---|
| `id` | INTEGER | PRIMARY KEY AUTOINCREMENT | Unique preference ID |
| `mac_id` | VARCHAR(64) | FOREIGN KEY → users(mac_id) | Which user |
| `node_id` | VARCHAR(50) | FOREIGN KEY → devices(node_id) | Which device |
| `sensor_type` | VARCHAR(50) | NOT NULL | Sensor name (e.g., 'temperature', 'accel_x') |
| `display_type` | VARCHAR(20) | NOT NULL | 'stripchart', 'numeric', 'both', 'none' |
| `created_at` | TIMESTAMP | DEFAULT CURRENT_TIMESTAMP | When preference created |
| `updated_at` | TIMESTAMP | DEFAULT CURRENT_TIMESTAMP | Last updated |

**Indexes:**
- PRIMARY KEY on `id`
- UNIQUE INDEX on `(mac_id, node_id, sensor_type)` (one preference per user/device/sensor combo)
- INDEX on `mac_id` (for fetching user's preferences)

**Constraints:**
- FOREIGN KEY `mac_id` REFERENCES `users(mac_id)` ON DELETE CASCADE
- FOREIGN KEY `node_id` REFERENCES `devices(node_id)` ON DELETE CASCADE
- UNIQUE (`mac_id`, `node_id`, `sensor_type`)
- CHECK: `display_type IN ('stripchart', 'numeric', 'both', 'none')`
- CHECK: `sensor_type IN ('temperature', 'pressure', 'light_intensity', 'accel_x', 'accel_y', 'accel_z', 'accel_norm', 'gyro_x', 'gyro_y', 'gyro_z', 'gyro_norm', 'mag_x', 'mag_y', 'mag_z', 'mag_norm', 'volume_rms', ...)`

**Example Data:**
```sql
INSERT INTO user_preferences (mac_id, node_id, sensor_type, display_type) VALUES (
  'a3f5b8c9d2e1f4g7h8i9j0k1l2m3n4o5p6q7r8s9t0u1v2w3x4y5z6a7b8c9d0e1f2',
  'LAB_01',
  'temperature',
  'both'  -- Show both stripchart AND numeric
);

INSERT INTO user_preferences (mac_id, node_id, sensor_type, display_type) VALUES (
  'a3f5b8c9d2e1f4g7h8i9j0k1l2m3n4o5p6q7r8s9t0u1v2w3x4y5z6a7b8c9d0e1f2',
  'LAB_01',
  'accel_norm',
  'stripchart'  -- Show only stripchart
);
```

**Usage Flow:**
1. User selects device (LAB_01)
2. User checks "Temperature - Stripchart" and "Temperature - Numeric"
3. Frontend sends: `{mac_id, node_id: 'LAB_01', sensor_type: 'temperature', display_type: 'both'}`
4. Backend stores in `user_preferences`
5. Next time user selects LAB_01, preferences are loaded and checkboxes pre-populated

---

## SQL Schema (SQLite)

```sql
-- Enable foreign keys (must run on each connection)
PRAGMA foreign_keys = ON;

-- Users table
CREATE TABLE users (
    mac_id VARCHAR(64) PRIMARY KEY,
    name VARCHAR(100) NOT NULL,
    grade VARCHAR(20),
    science_interest TEXT,
    first_seen TIMESTAMP DEFAULT CURRENT_TIMESTAMP,
    last_seen TIMESTAMP DEFAULT CURRENT_TIMESTAMP
);

CREATE INDEX idx_users_last_seen ON users(last_seen);

-- Devices table
CREATE TABLE devices (
    node_id VARCHAR(50) PRIMARY KEY,
    hostname VARCHAR(100),
    ip_address VARCHAR(15),
    last_seen TIMESTAMP DEFAULT CURRENT_TIMESTAMP,
    is_active BOOLEAN DEFAULT TRUE
);

CREATE INDEX idx_devices_last_seen ON devices(last_seen);
CREATE INDEX idx_devices_active ON devices(is_active, last_seen);

-- Sensor data table (time-series)
CREATE TABLE sensor_data (
    id INTEGER PRIMARY KEY AUTOINCREMENT,
    node_id VARCHAR(50) NOT NULL,
    timestamp TIMESTAMP DEFAULT CURRENT_TIMESTAMP,
    esp_timestamp INTEGER,
    temperature REAL,
    pressure REAL,
    light_intensity REAL,
    accel_x REAL,
    accel_y REAL,
    accel_z REAL,
    accel_norm REAL,
    gyro_x REAL,
    gyro_y REAL,
    gyro_z REAL,
    gyro_norm REAL,
    mag_x REAL,
    mag_y REAL,
    mag_z REAL,
    mag_norm REAL,
    volume_rms REAL,
    spectral_f1_405nm REAL,
    spectral_f2_425nm REAL,
    spectral_f3_475nm REAL,
    spectral_f4_515nm REAL,
    spectral_fz_450nm REAL,
    spectral_fy_555nm REAL,
    spectral_f5_550nm REAL,
    spectral_f6_640nm REAL,
    spectral_fxl_600nm REAL,
    spectral_f7_690nm REAL,
    spectral_f8_745nm REAL,
    spectral_nir_855nm REAL,
    spectral_vis REAL,
    spectral_fd REAL,
    FOREIGN KEY (node_id) REFERENCES devices(node_id) ON DELETE CASCADE
);

CREATE INDEX idx_sensor_data_node_id ON sensor_data(node_id);
CREATE INDEX idx_sensor_data_timestamp ON sensor_data(timestamp);
CREATE INDEX idx_sensor_data_node_timestamp ON sensor_data(node_id, timestamp DESC);

-- Questions table
CREATE TABLE questions (
    id INTEGER PRIMARY KEY AUTOINCREMENT,
    question_text TEXT NOT NULL,
    question_type VARCHAR(20) NOT NULL CHECK(question_type IN ('multiple_choice', 'free_text')),
    options TEXT,  -- JSON array for multiple choice
    created_at TIMESTAMP DEFAULT CURRENT_TIMESTAMP,
    is_active BOOLEAN DEFAULT TRUE,
    created_by VARCHAR(100)
);

CREATE INDEX idx_questions_active ON questions(is_active, created_at DESC);

-- Answers table
CREATE TABLE answers (
    id INTEGER PRIMARY KEY AUTOINCREMENT,
    question_id INTEGER NOT NULL,
    mac_id VARCHAR(64) NOT NULL,
    answer TEXT NOT NULL,
    answered_at TIMESTAMP DEFAULT CURRENT_TIMESTAMP,
    FOREIGN KEY (question_id) REFERENCES questions(id) ON DELETE CASCADE,
    FOREIGN KEY (mac_id) REFERENCES users(mac_id) ON DELETE CASCADE,
    UNIQUE(question_id, mac_id)  -- Prevent duplicate answers
);

CREATE INDEX idx_answers_question_id ON answers(question_id);
CREATE INDEX idx_answers_mac_id ON answers(mac_id);

-- User preferences table
CREATE TABLE user_preferences (
    id INTEGER PRIMARY KEY AUTOINCREMENT,
    mac_id VARCHAR(64) NOT NULL,
    node_id VARCHAR(50) NOT NULL,
    sensor_type VARCHAR(50) NOT NULL,
    display_type VARCHAR(20) NOT NULL CHECK(display_type IN ('stripchart', 'numeric', 'both', 'none')),
    created_at TIMESTAMP DEFAULT CURRENT_TIMESTAMP,
    updated_at TIMESTAMP DEFAULT CURRENT_TIMESTAMP,
    FOREIGN KEY (mac_id) REFERENCES users(mac_id) ON DELETE CASCADE,
    FOREIGN KEY (node_id) REFERENCES devices(node_id) ON DELETE CASCADE,
    UNIQUE(mac_id, node_id, sensor_type)
);

CREATE INDEX idx_user_preferences_mac_id ON user_preferences(mac_id);
CREATE UNIQUE INDEX idx_user_preferences_unique ON user_preferences(mac_id, node_id, sensor_type);
```

---

## Query Examples

### Get Active Devices
```sql
SELECT node_id, hostname, last_seen
FROM devices
WHERE last_seen > datetime('now', '-5 seconds')
ORDER BY last_seen DESC;
```

### Get Recent Sensor Data for Device
```sql
SELECT timestamp, temperature, pressure, light_intensity
FROM sensor_data
WHERE node_id = 'LAB_01'
  AND timestamp > datetime('now', '-1 hour')
ORDER BY timestamp DESC
LIMIT 1000;
```

### Get User's Unanswered Questions
```sql
SELECT q.id, q.question_text, q.question_type, q.options
FROM questions q
LEFT JOIN answers a ON q.id = a.question_id AND a.mac_id = ?
WHERE q.is_active = TRUE
  AND a.id IS NULL;
```

### Get User's Preferences for Device
```sql
SELECT sensor_type, display_type
FROM user_preferences
WHERE mac_id = ?
  AND node_id = ?;
```

### Clean Up Old Sensor Data
```sql
DELETE FROM sensor_data
WHERE timestamp < datetime('now', '-24 hours');
```

---

## Database Maintenance

### Periodic Tasks (Cron/Systemd Timer)

1. **Sensor Data Cleanup** (every hour)
```bash
sqlite3 dashboard.db "DELETE FROM sensor_data WHERE timestamp < datetime('now', '-24 hours');"
```

2. **VACUUM** (weekly, reclaim space)
```bash
sqlite3 dashboard.db "VACUUM;"
```

3. **Analyze** (weekly, update query planner statistics)
```bash
sqlite3 dashboard.db "ANALYZE;"
```

### Backup Strategy

1. **Daily Backup** (retain 7 days)
```bash
sqlite3 dashboard.db ".backup /var/backups/dashboard_$(date +%Y%m%d).db"
```

2. **Before Schema Changes**
```bash
cp dashboard.db dashboard.db.backup
```

---

## Performance Considerations

### Write Performance
- **Expected**: 500 writes/sec (10 devices @ 50 Hz)
- **SQLite Limit**: 50,000+ writes/sec (WAL mode)
- **Bottleneck**: Network (UDP packet processing)
- **Optimization**: Batch inserts (10-100 records per transaction)

### Read Performance
- **Expected**: 10-100 reads/sec (WebSocket broadcasts)
- **SQLite Limit**: Unlimited concurrent reads (WAL mode)
- **Optimization**: Proper indexing, query caching

### Storage Growth
- **Rate**: ~100 MB/hour (10 devices @ 50 Hz, all sensors)
- **With 24-hour retention**: ~2.4 GB steady-state
- **Mitigation**: Regular cleanup, WAL checkpointing

---

## Schema Versioning

Track schema changes for migrations:

```sql
CREATE TABLE schema_version (
    version INTEGER PRIMARY KEY,
    applied_at TIMESTAMP DEFAULT CURRENT_TIMESTAMP,
    description TEXT
);

INSERT INTO schema_version (version, description) VALUES
(1, 'Initial schema with users, devices, sensor_data, questions, answers, user_preferences');
```

Future migrations:
```python
# Example migration script
def migrate_v1_to_v2(db):
    db.execute("ALTER TABLE users ADD COLUMN email VARCHAR(100);")
    db.execute("INSERT INTO schema_version (version, description) VALUES (2, 'Add email to users');")
```

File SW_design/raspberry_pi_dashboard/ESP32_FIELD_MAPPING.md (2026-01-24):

# ESP32 JSON Field Mapping to Dashboard

This document shows how ESP32 sensor data fields map to the dashboard measurement displays.

## Data Flow

```
ESP32 Sensor
    ↓ UDP JSON Packet (port 5000)
Backend (udp_listener.py)
    ↓ Store in Database
    ↓ WebSocket Broadcast (Socket.IO)
Frontend (pocket-lab-live.js)
    ↓ handleSensorData()
    ↓ extractSensorValue()
    ↓ updateDisplay()
Live Dashboard Display
```

## Field Mappings

All mappings are implemented in `extractSensorValue()` function in `pocket-lab-live.js`.

### 1. Temperature
**JSON Field:** `temperature`
**Measurement Card:** Temperature
**Unit:** °C
**Color:** RED (#bd2026)
**Code:**
```javascript
case 'temperature':
    return data.temperature;
```

### 2. Pressure
**JSON Field:** `pressure`
**Measurement Card:** Pressure
**Unit:** kPa
**Color:** BLUE (#375f83)
**Code:**
```javascript
case 'pressure':
    return data.pressure;
```

### 3. Ambient Light
**JSON Field:** `light_intensity`
**Measurement Card:** Ambient Light
**Unit:** lux
**Color:** AMBER/GOLD (#fbbf24)
**Code:**
```javascript
case 'ambientLight':
    return data.light_intensity;
```

### 4. Acceleration (Vector)
**JSON Fields:** `accel_x`, `accel_y`, `accel_z`, `accel_norm`
**Measurement Card:** Acceleration
**Unit:** m/s²
**Color:** GREEN (#10b981)
**Display Types:**
- Time-graph: Shows all 4 components (X, Y, Z, Norm)
- Numeric Only: User selects component (dropdown)
- Numeric w. Statistics: User selects component (dropdown)
- Vector: 3D visualization with all components

**Code:**
```javascript
case 'acceleration':
    return {
        x: data.accel_x || 0,
        y: data.accel_y || 0,
        z: data.accel_z || 0,
        norm: data.accel_norm || 0
    };
```

### 5. Gyroscope (Vector)
**JSON Fields:** `gyro_x`, `gyro_y`, `gyro_z`, `gyro_norm`
**Measurement Card:** Gyroscope
**Unit:** deg/s
**Color:** ORANGE (#f97316)
**Display Types:** Same as Acceleration

**Code:**
```javascript
case 'gyro':
    return {
        x: data.gyro_x || 0,
        y: data.gyro_y || 0,
        z: data.gyro_z || 0,
        norm: data.gyro_norm || 0
    };
```

### 6. Magnetometer (Vector)
**JSON Fields:** `mag_x`, `mag_y`, `mag_z`, `mag_norm`
**Measurement Card:** Magnetometer
**Unit:** µT
**Color:** YELLOW (#f8c01c)
**Display Types:** Same as Acceleration

**Code:**
```javascript
case 'magnetometer':
    return {
        x: data.mag_x || 0,
        y: data.mag_y || 0,
        z: data.mag_z || 0,
        norm: data.mag_norm || 0
    };
```

### 7. Volume
**JSON Field:** `volume_rms`
**Measurement Card:** Volume
**Unit:** dB
**Color:** PINK/MAGENTA (#d782a0)
**Code:**
```javascript
case 'volume':
    return data.volume_rms;
```

### 8. Light Spectrum (Optional)
**JSON Fields:** `spectral_f1_405nm`, `spectral_f2_425nm`, ..., `spectral_nir_855nm`
**Measurement Card:** Light Spectrum (only shows if data present)
**Unit:** Intensity (raw values)
**Color:** PURPLE (#8b5cf6)
**Note:** This card auto-hides if no spectral data is sent

**Code:**
```javascript
case 'spectrum':
    return {
        wavelengths: [405, 425, 475, 515, 450, 555, 550, 640, 600, 690, 745, 855],
        names: ['F1', 'F2', 'F3', 'F4', 'FZ', 'FY', 'F5', 'F6', 'FXL', 'F7', 'F8', 'NIR'],
        values: [
            data.spectral_f1_405nm || 0,
            data.spectral_f2_425nm || 0,
            data.spectral_f3_475nm || 0,
            data.spectral_f4_515nm || 0,
            data.spectral_fz_450nm || 0,
            data.spectral_fy_555nm || 0,
            data.spectral_f5_550nm || 0,
            data.spectral_f6_640nm || 0,
            data.spectral_fxl_600nm || 0,
            data.spectral_f7_690nm || 0,
            data.spectral_f8_745nm || 0,
            data.spectral_nir_855nm || 0
        ]
    };
```

## Color Usage

### Numeric Displays
The large numeric value now displays in the measurement's specific color:
- Temperature: RED text
- Pressure: BLUE text
- Acceleration: GREEN text
- Gyroscope: ORANGE text
- Magnetometer: YELLOW text
- Volume: PINK text
- Ambient Light: AMBER/GOLD text

### Cards
- **Card Border:** Measurement color
- **Icon Background:** Measurement color at 20% opacity
- **Icon:** Measurement color
- **Display Badge:** Measurement color background

## Sensor Detection

The dashboard automatically detects which sensors are available:

1. **Initially:** Shows all measurement cards
2. **After first packet:** Hides cards for sensors without data
3. **Checking logic:** `hasSensorData()` function checks if fields exist in JSON

Example: If your ESP32 doesn't send `spectral_f1_405nm`, the Light Spectrum card will automatically disappear.

## Display Types

### Time-graph
- Rolling window (5s to 5min configurable)
- For vectors: plots all 4 components (X, Y, Z, Norm) on same graph
- For scalars: single line
- Updates in real-time as data arrives

### Numeric Only
- Shows current value only
- For vectors: dropdown to select X/Y/Z/Norm
- Color matches measurement type
- Shows timestamp

### Numeric w. Statistics
- Current value (colored), Average, Min, Max, Std Deviation, Sample Count
- For vectors: dropdown to select component (auto-resets stats when changed)
- Reset button to clear statistics
- Cumulative statistics since display opened or reset

### Vector (IMU only)
- 3D isometric visualization
- Shows X (yellow), Y (blue), Z (pink) axes
- Red vector arrow with magnitude
- Component breakdown below visualization

### Electromagnetic Spectrum (AS7343 only)
- Bar chart with 12 channels
- Rainbow gradient colors
- Wavelength labels (405nm - 855nm)
- Only appears if spectral data is sent

## Troubleshooting

### Data not updating
1. Check debug console for "📊 Processing sensor data from..." messages
2. Verify ESP32 is sending all required fields in JSON
3. Check field names match exactly (case-sensitive)
4. Open browser console (F12) for JavaScript errors

### Measurement card not showing
1. Card auto-hides if no data is sent for that sensor
2. Check ESP32 JSON includes the required field
3. Wait for first data packet after selecting device
4. Check debug console for "⏭️ Skipping..." messages

### Wrong values displayed
1. Verify ESP32 sends correct units (°C, kPa, m/s², deg/s, µT, dB, lux)
2. Check for NaN or null values in JSON
3. Vector fields must all be present (x, y, z, norm)
4. Numeric displays show 2 decimal places

## Example ESP32 JSON Packet

```json
{
  "node_id": "LAB_01",
  "timestamp": 1234567890,
  "temperature": 23.45,
  "pressure": 101.32,
  "light_intensity": 542.18,
  "accel_x": 0.123,
  "accel_y": -0.056,
  "accel_z": 9.812,
  "accel_norm": 9.813,
  "gyro_x": 0.023,
  "gyro_y": -0.011,
  "gyro_z": 0.002,
  "gyro_norm": 0.026,
  "mag_x": 25.34,
  "mag_y": -12.78,
  "mag_z": 48.92,
  "mag_norm": 56.43,
  "volume_rms": -28.5
}
```

**Note:** Spectral fields omitted = Light Spectrum card automatically hidden.

---

**All connections are live and working!** Simply select a device, pick measurements, and watch real-time ESP32 data flow into the displays.

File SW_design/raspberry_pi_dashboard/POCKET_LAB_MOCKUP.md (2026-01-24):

# Pocket Lab Data Tab - Mockup

## Quick Access

**URL:** http://localhost:8080/pocket-lab-mockup.html

(Or from network: http://192.168.10.2:8080/pocket-lab-mockup.html)

---

## What This Mockup Demonstrates

This is a **fully interactive mockup** of the Pocket Lab Data tab with **mock data generation**. You can interact with all features without connecting to actual ESP32 devices.

### Flow:

1. **Device Selection (Step 1)**
   - View 4 mock ESP32 devices
   - Click on any device to select it
   - Device cards show: name, ID, IP, active status, last seen

2. **Measurement Selection (Step 2)**
   - After selecting a device, see 8 measurement cards:
     - Temperature
     - Pressure
     - Acceleration (vector)
     - Gyroscope (vector)
     - Magnetometer (vector)
     - Volume
     - Ambient Light
     - Light Spectrum

   - Each card shows available display options as **outline buttons**:
     - **Regular sensors:** Time-graph, Numeric Only, Numeric w. Statistics
     - **Vector quantities:** Time-graph, Numeric Only, Numeric w. Statistics, Vector
     - **Light Spectrum:** Electromagnetic Spectrum only

3. **Data Display (Step 3)**
   - Click any button → it becomes a **primary button** (filled)
   - A new display card appears below
   - Click multiple buttons → multiple cards are created
   - Each card shows live mock data

---

## Display Types Explained

### 🔢 Numeric Only
- Shows the **last received value** in large text
- Updates every second with mock data
- Timestamp shows when last updated

### 📊 Numeric w. Statistics
- Shows **6 statistics**:
  - Current value
  - Average
  - Minimum
  - Maximum
  - Standard Deviation
  - Sample Count
- Rolling statistics (all data since display created)
- **Reset button** to clear statistics window

### 📈 Time-graph
- **10-second scrolling window** (shows last ~50 data points)
- **Auto-scaling Y-axis**
- For vectors (Accel, Gyro, Mag):
  - Shows **all 4 components** on same graph: X, Y, Z, Norm
  - Color-coded with legend
  - Example colors:
    - X: Yellow
    - Y: Blue
    - Z: Pink
    - Norm: Red

### 🎯 Vector (Vector quantities only)
- **2D projection** of 3D vector (X-Y magnitude vs Z)
- Shows scatter plot with origin
- **Component breakdown**:
  - X component
  - Y component
  - Z component
  - Magnitude (norm)
- Updates in real-time

### 🌈 Electromagnetic Spectrum (Light spectrum only)
- **Bar chart** showing intensity at each wavelength
- **12 spectral channels**:
  - F1 (405nm) - Violet/UV
  - F2 (425nm) - Dark Blue
  - F3 (475nm) - Light Blue
  - F4 (515nm) - Blue
  - FZ (450nm) - Blue (alternate)
  - FY (555nm) - Green
  - F5 (550nm) - Green (narrow)
  - F6 (640nm) - Orange
  - FXL (600nm) - Orange (extended)
  - F7 (690nm) - Red
  - F8 (745nm) - Dark Red
  - NIR (855nm) - Near Infrared
- Color-coded bars matching actual spectrum

---

## Interactive Features

### Selecting/Deselecting Displays
- **Click outline button** → becomes primary, adds display
- **Click primary button** → becomes outline, removes display
- **Click X button** on display card → removes display and resets button

### Changing Device
- Click **"Change Device"** button in top banner
- Returns to device selection
- **Clears all active displays**

### Theme Switching
- Click **theme toggle** in top-right
- Switch between light and dark mode
- Preference saved in browser

### Statistics Reset
- Click **"Reset Statistics"** button on stats displays
- Clears all accumulated data
- Starts fresh from next update

---

## Mock Data Behavior

All data is **randomly generated** to simulate real sensors:

- **Temperature:** 23.5°C ± 1.5°C
- **Pressure:** 101.3 kPa ± 0.5 kPa
- **Volume:** -25 dB ± 10 dB
- **Ambient Light:** 542 lux ± 100 lux
- **Acceleration/Gyro/Mag:** Random 3D vectors
- **Spectrum:** Random intensities for each wavelength

**Update rate:** 1 Hz (1 update per second)

---

## Testing Checklist

Please test and provide feedback on:

### Layout & Organization
- [ ] Is the device selection grid clear?
- [ ] Are measurement cards easy to understand?
- [ ] Is the selected device banner prominent enough?
- [ ] Do display cards have good spacing?
- [ ] Does the layout work on different screen sizes?

### Button Behavior
- [ ] Is the outline → primary button transition clear?
- [ ] Are button labels descriptive?
- [ ] Is it obvious which options are selected?

### Display Cards
- [ ] **Numeric Only:** Is the value readable? Font size OK?
- [ ] **Statistics:** Are all 6 stats clearly labeled?
- [ ] **Time-graph:** Is the 10-second window clear? Legend readable?
- [ ] **Vector:** Does the 2D projection make sense? Are components clear?
- [ ] **Spectrum:** Are wavelengths and colors distinguishable?

### User Flow
- [ ] Is it intuitive to select a device?
- [ ] Is it clear how to add displays?
- [ ] Is it easy to remove displays?
- [ ] Is the "Change Device" button findable?
- [ ] Can you easily compare multiple displays?

### Visual Design
- [ ] Do colors match brand (yellow, blue, pink, red)?
- [ ] Is Work Sans font rendering well?
- [ ] Do both light and dark themes look good?
- [ ] Are cards and borders visually appealing?
- [ ] Is there good contrast for readability?

### Performance
- [ ] Are charts updating smoothly?
- [ ] Can you add 10+ displays without lag?
- [ ] Do statistics calculate correctly?
- [ ] Are animations smooth?

---

## Known Limitations (Mockup Only)

- No real ESP32 connection
- Data is randomly generated
- No actual device discovery
- Statistics are in-memory only (reset on page reload)
- Vector display is 2D projection of 3D space

These will be addressed when connecting to real backend.

---

## Providing Feedback

Please review and let me know:

1. **What looks good?**
2. **What needs improvement?**
3. **Are there any confusing elements?**
4. **Should any layouts change?**
5. **Are the display types what you envisioned?**

Specific feedback appreciated:
- "The time-graph needs a bigger legend"
- "Statistics should be in 3 columns instead of 2"
- "Vector display is confusing, needs labels"
- "Love the spectrum colors!"
- etc.

---

## Next Steps After Approval

Once you approve the layout:
1. Connect to real WebSocket backend
2. Integrate with ESP32 UDP data
3. Add user preference persistence (save selections)
4. Implement advanced features (export data, etc.)
5. Optimize performance for Raspberry Pi

---

**Enjoy exploring the mockup!** 🚀

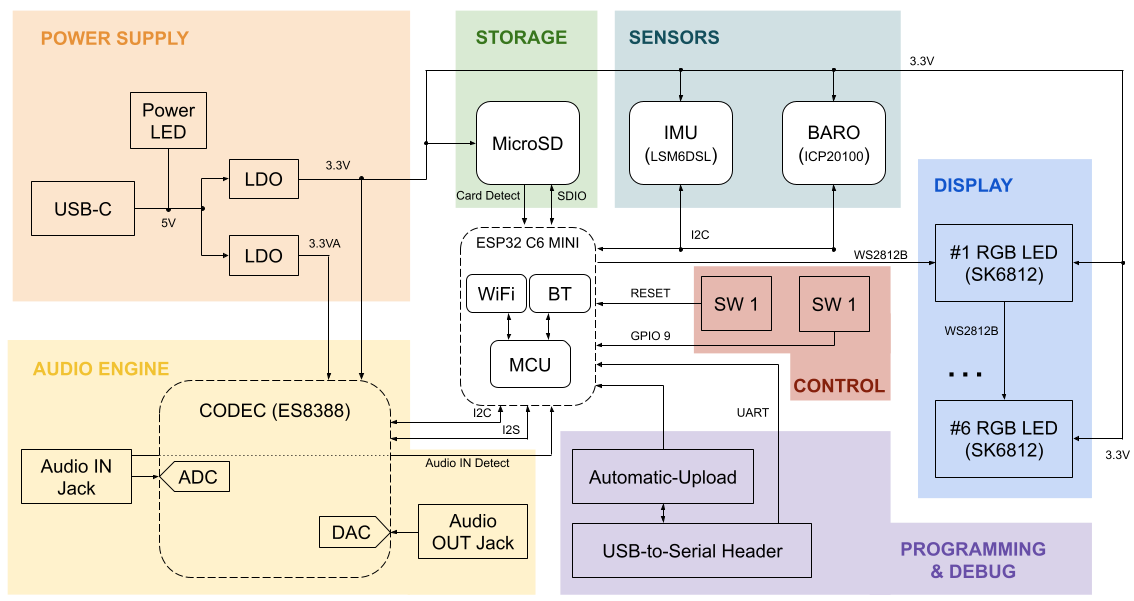
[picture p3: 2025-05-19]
Resources/schematic_functional_dev_v0.png

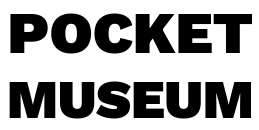
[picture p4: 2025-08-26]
Resources/PCB Graphics/PocketMuseum.png

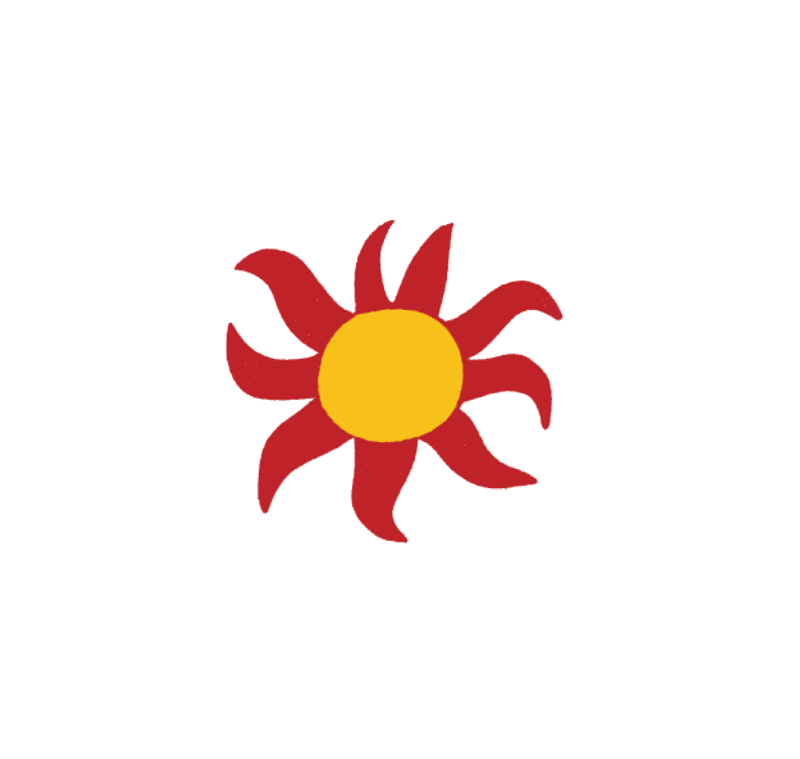
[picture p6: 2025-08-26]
Resources/PCB Graphics/BASM_sun.png

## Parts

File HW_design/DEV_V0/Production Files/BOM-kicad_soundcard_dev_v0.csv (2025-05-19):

Comment | Designator | Footprint | LCSC | Quantity
DM3AT-SF-PEJM5 | J201 | microSD_HC_Hirose_DM3AT-SF-PEJM5 | C114218 | 1
1k | R413,R414,R421,R422 | R_0402_1005Metric | C11702 | 4
LSM6DSL | U301 | LGA-14_3x2.5mm_P0.5mm_LayoutBorder3x4y | C126672 | 1
47u | C105,C424,C425 | C_0603_1608Metric | C140782 | 3
1u | C101,C102,C205,C301,C302,C303,C304,C305,C306,C418,C420,C422 | C_0402_1005Metric | C14445 | 12
0u1 | C202,C203,C204,C207,C307,C308,C309,C310,C402,C404,C406,C407,C409,C411,C415,C416,C417,C419,C421 | C_0402_1005Metric | C1525 | 19
0R | R103,R214,R215,R216,R217,R218,R219,R221,R301,R302,R303,R304,R418,R419,R420 | R_0603_1608Metric | C15402 | 15
20p | C413,C414 | C_0402_1005Metric | C1554 | 2
BM04B-SRSS-TB | J204,J205,J206 | JST_SH_BM04B-SRSS-TB_1x04-1MP_P1.00mm_Vertical | C160390 | 3
USB_C_Receptacle_USB2.0_16P | J101 | USB_C_Receptacle_HRO_TYPE-C-31-M-12 | C165948 | 1
10u | C201,C206,C401,C403,C405,C408,C410,C412,C423 | C_0603_1608Metric | C1691 | 9
2R2 | R106 | R_1206_3216Metric | C17947 | 1
LED | D103 | LED_0402_1005Metric | C21260817 | 1
10R | R105,R416,R417 | R_0603_1608Metric | C22859 | 3
33R | R404,R405,R406,R407,R408 | R_0402_1005Metric | C25105 | 5
470R | R203 | R_0402_1005Metric | C25117 | 1
4R7 | R403 | R_0402_1005Metric | C25121 | 1
100R | R401,R409,R410 | R_0402_1005Metric | C25138 | 3
100k | R412 | R_0402_1005Metric | C25741 | 1
10k | R204,R205,R206,R207,R208,R209,R210,R211,R212,R213,R220,R423,R424 | R_0402_1005Metric | C25744 | 13
5k1 | R101,R102,R201,R202 | R_0402_1005Metric | C25905 | 4
PTS636 | SW201,SW202 | SW_Tactile_SPST_NO_Straight_CK_PTS636Sx25SMTRLFS | C2689642 | 2
1x6P 2.54mm SMD | J202,J203 | PinHeader_1x06_P2.54mm_Vertical_SMD_Pin1Right | C2883803 | 2
SK6805-EC20 | D301,D302,D303,D304,D305,D306 | SK68xx-EC20 | C2890036 | 6
PJ31060-I | J401,J402 | Jack_3.5mm_PJ31060-I_Horizontal | C2939583 | 2
AMS1117-3.3 | U101,U102 | SOT-223-3_TabPin2 | C347222 | 2
LESD5D5.0CT1G | D101,D102,D201,D202,D203,D204,D205 | D_SOD-523 | C383211 | 7
2k | R104,R402,R411,R415 | R_0402_1005Metric | C4109 | 4
L8050QLT1G | Q201,Q202 | SOT-23 | C49581 | 2
ICP20100 | U302 | ST_HLGA-10_2x2mm_P0.5mm_LayoutBorder3x2y | C5343527 | 1
ESP32-C6-MINI-1/U | U201 | ESP32-C6-MINI-1 | C5736265 | 1
10n | L101 | L_0402_1005Metric | C77103 | 1
BSS138LT3G | Q401,Q402 | SOT-23 | C83790 | 2
22u | C103,C104,C106 | C_0603_1608Metric | C86295 | 3
ES8388 | U401 | QFN-28-1EP_4x4mm_P0.45mm_EP2.6x2.6mm |  | 1

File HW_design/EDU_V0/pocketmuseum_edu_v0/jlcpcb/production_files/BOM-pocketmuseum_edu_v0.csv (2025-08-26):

Comment | Designator | Footprint | LCSC | Quantity
TF-015 | J201 | TF-015_SOFNG | C113206 | 1
1k | R308 | R_0402_1005Metric | C11702 | 1
1u | C101,C102,C105,C204,C301,C307,C401,C402,C403,C404,C405,C406,C407,C408,C409 | C_0402_1005Metric | C14445 | 15
0u1 | C106,C202,C203,C207,C302,C303,C304,C305,C306,C308 | C_0402_1005Metric | C1525 | 10
SM04B-SRSS-TB | J205,J206 | JST_SH_SM04B-SRSS-TB_1x04-1MP_P1.00mm_Horizontal | C160404 | 2
USB_C_Receptacle_USB2.0_16P | J101 | USB_C_Receptacle_HRO_TYPE-C-31-M-12 | C165948 | 1
10u | C103,C104,C107,C108,C109,C110,C201,C206 | C_0603_1608Metric | C1691 | 8
AP2112K-1.8 | U104 | SOT-23-5 | C176944 | 1
BAT54C | D104 | SOT-23 | C181200 | 1
0R | R114,R208 | R_0603_1608Metric | C21189 | 2
LED | D208 | LED_0402_1005Metric | C21260817 | 1
PTS810SJG250 | SW101,SW201 | SW_SPST_PTS810 | C221895 | 2
470R | R203 | R_0402_1005Metric | C25117 | 1
100k | R110 | R_0402_1005Metric | C25741 | 1
10k | R105,R106,R107,R112,R113,R204,R205,R206,R207,R209,R210,R211,R212,R213,R214,R305 | R_0402_1005Metric | C25744 | 16
1k2 | R103,R215 | R_0402_1005Metric | C25862 | 2
3k3 | R111 | R_0402_1005Metric | C25890 | 1
5k1 | R101,R102,R201,R202,R301,R302,R303,R304 | R_0402_1005Metric | C25905 | 8
6k8 | R104 | R_0402_1005Metric | C25917 | 1
178k | R109 | R_0402_1005Metric | C26995 | 1
SK6805-EC20 | D401,D402,D403,D404,D405,D406,D407,D408,D409 | SK68xx-EC20 | C2890036 | 9
JST PH S2B | J102 | JST_PH_S2B-PH-SM4-TB_1x02-1MP_P2.00mm_Horizontal | C295747 | 1
T3902 | U304 | MMIC | C3171752 | 1
61k9 | R108 | R_0402_1005Metric | C327331 | 1
APX803-29SAG | U102 | SOT-23 | C460551 | 1
AP2112K-3.3 | U103 | SOT-23-5 | C51118 | 1
LESD5D5.0CT1G | D101,D102,D103 | D_SOD-523 | C5199850 | 3
ICP20100 | U302 | ST_HLGA-10_2x2mm_P0.5mm_LayoutBorder3x2y | C5343527 | 1
ESP32-C6-MINI-1/U | U201 | ESP32-C6-MINI-1 | C5736265 | 1
ICM-20948 | U301 | InvenSense_QFN-24_3x3mm_P0.4mm | C726001 | 1
10n | L101 | L_0402_1005Metric | C77103 | 1
BH1750FVI | U303 | XDCR_BH1750FVI-TR | C78960 | 1
BQ24040 | U101 | QFN_10_BQ24040 | C81080 | 1
BSS138 | Q301,Q302,Q303 | SOT-23 | C8490 | 3
TestPoint | TP105 | TestPoint_Pad_D2.0mm |  | 1
TestPoint | TP101 | TestPoint_Pad_D2.0mm |  | 1
TestPoint | TP104 | TestPoint_Pad_D2.0mm |  | 1
TestPoint | TP102 | TestPoint_Pad_D2.0mm |  | 1
TestPoint | TP103 | TestPoint_Pad_D2.0mm |  | 1

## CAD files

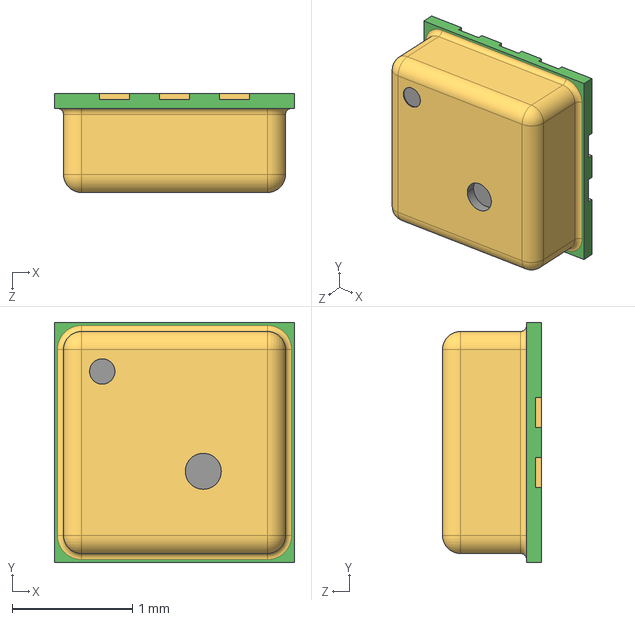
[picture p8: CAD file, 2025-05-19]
HW_design/DEV_V0/CAD Models/ICP-20100/3D/ICP-20100.stp
2.00 x 2.00 x 0.825 mm

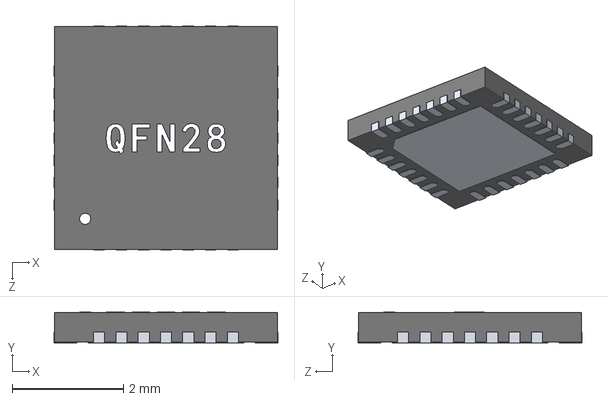
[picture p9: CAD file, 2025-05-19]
HW_design/DEV_V0/CAD Models/QFN284x404p.step
4.02 x 0.555 x 4.02 mm

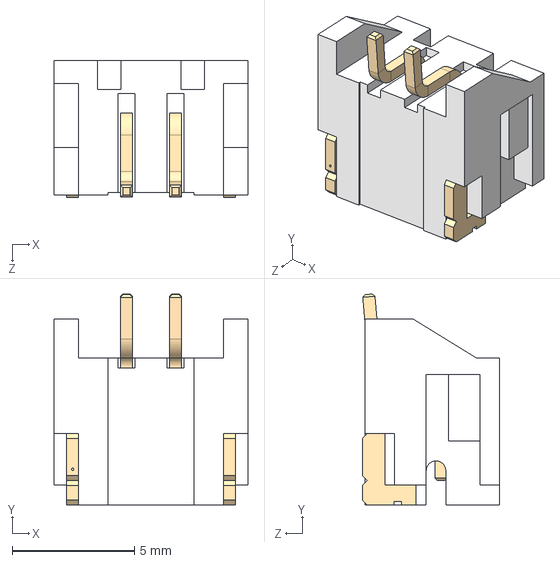
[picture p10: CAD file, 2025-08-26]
Resources/CAD Models/JST-S2B-PH-SM4-TB.STEP
7.90 x 8.61 x 5.61 mm

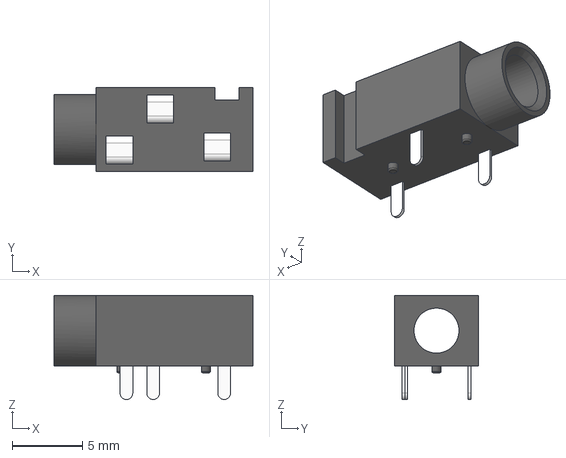
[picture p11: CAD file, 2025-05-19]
HW_design/DEV_V0/CAD Models/PJ-320.stp
14.2 x 6.00 x 7.40 mm

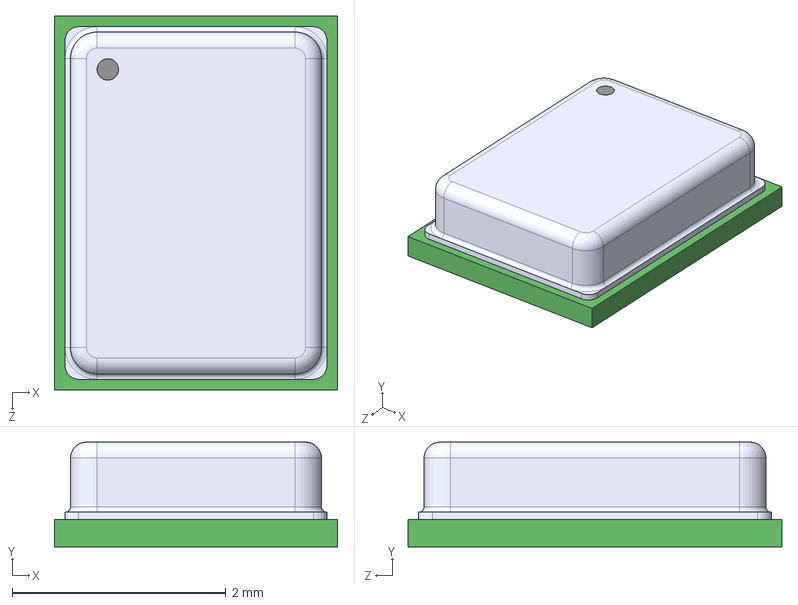
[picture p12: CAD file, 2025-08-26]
Resources/CAD Models/T3902.step
2.65 x 0.98 x 3.50 mm

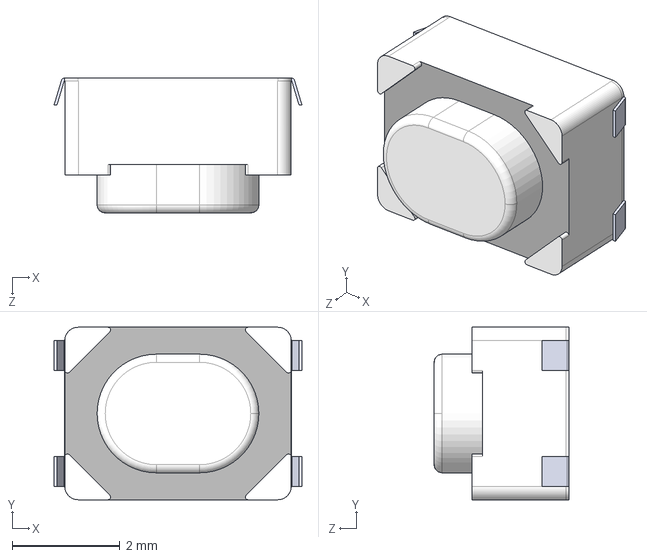
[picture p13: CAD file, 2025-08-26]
Resources/CAD Models/PTS810 Series SJS 250.STEP
4.60 x 3.20 x 2.50 mm

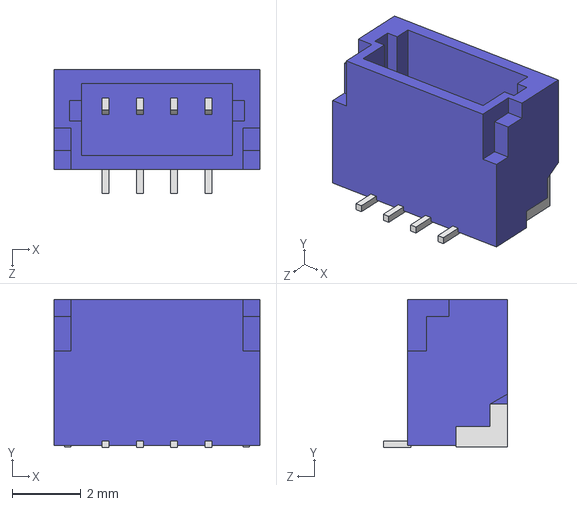
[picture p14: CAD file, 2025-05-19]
HW_design/DEV_V0/CAD Models/BM04B-SRSS-TB.STEP
6.00 x 4.32 x 3.60 mm

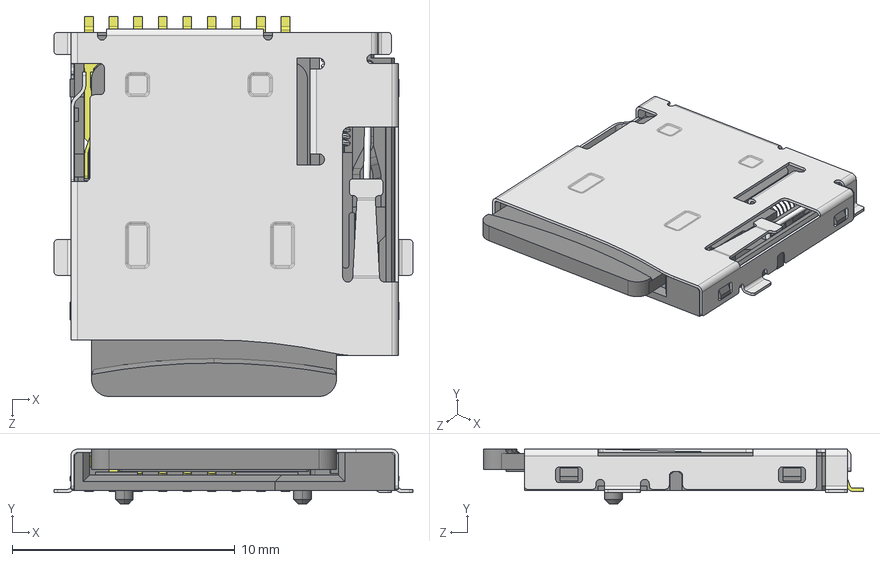
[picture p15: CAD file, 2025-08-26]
Resources/CAD Models/MicroSD_Socket.STEP
16.1 x 2.45 x 17.0 mm
Case^MicroSD_Socket
Insert^MicroSD_Socket
Brace^MicroSD_Socket
Spring^MicroSD_Socket
Lid^MicroSD_Socket
Pin_Middle^MicroSD_Socket x 5
Pin_Short^MicroSD_Socket
Pin_Long^MicroSD_Socket x 2
MicroSD_Card^MicroSD_Socket
Pin_CardIn^MicroSD_Socket

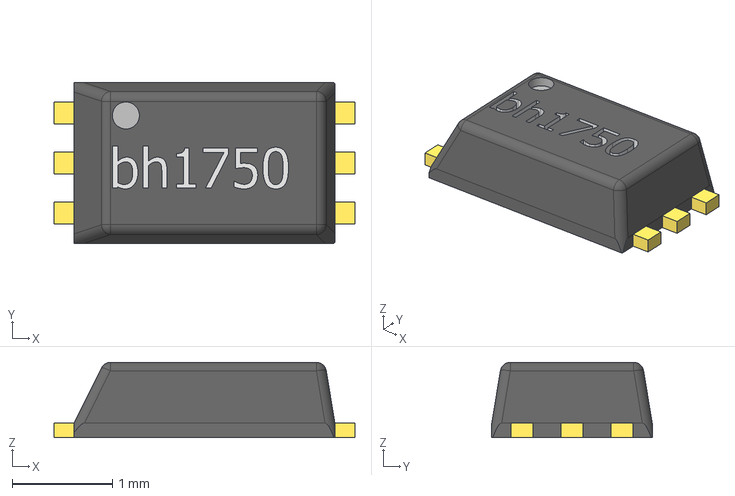
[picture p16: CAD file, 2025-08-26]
Resources/CAD Models/bh1750.stp
3.00 x 1.60 x 0.75 mm

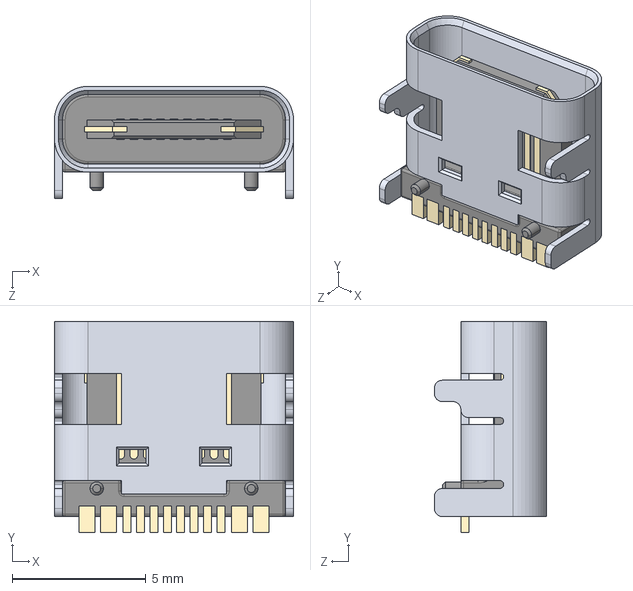
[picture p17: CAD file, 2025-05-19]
HW_design/DEV_V0/CAD Models/USB Type C Port (SMD Type).STEP
8.94 x 7.90 x 4.20 mm

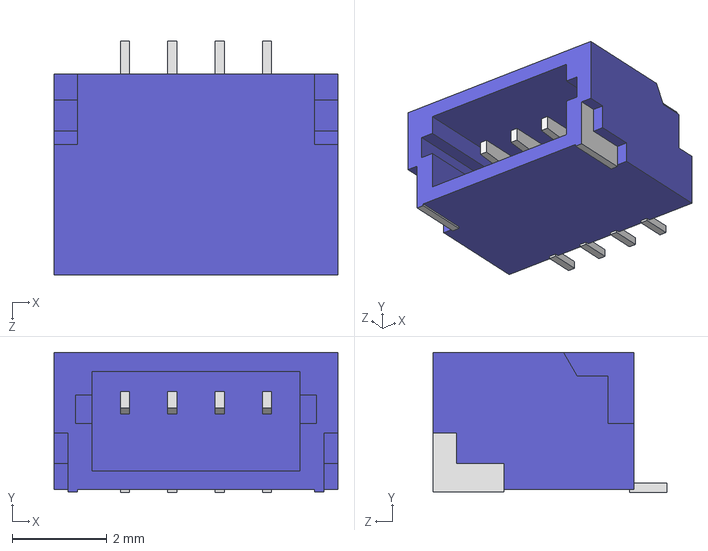
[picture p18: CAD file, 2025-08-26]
Resources/CAD Models/SM04B-SRSS-TB.STEP
6.00 x 2.96 x 4.95 mm

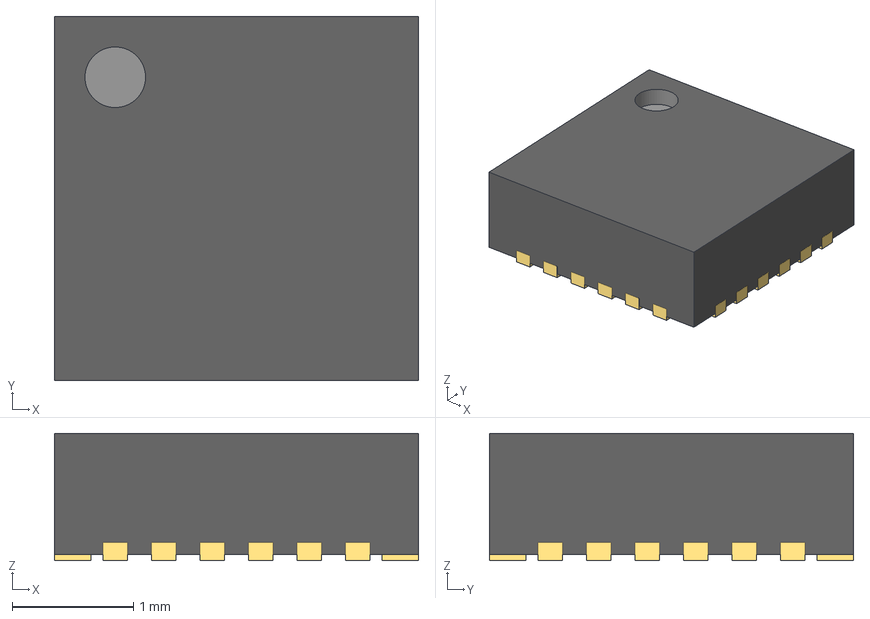
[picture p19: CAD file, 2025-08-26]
Resources/CAD Models/QFN-24 3x3 0.4mm.stp
3.00 x 3.00 x 1.05 mm

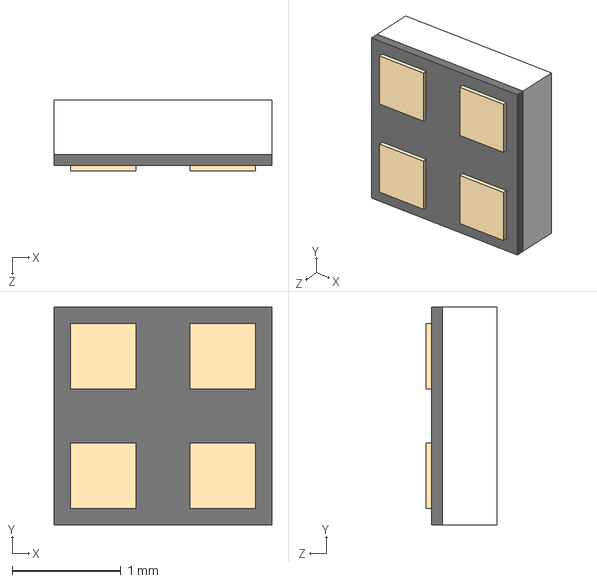
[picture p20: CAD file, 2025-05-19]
Resources/CAD Models/SK6812-EC20.STEP
2.00 x 2.00 x 0.65 mm

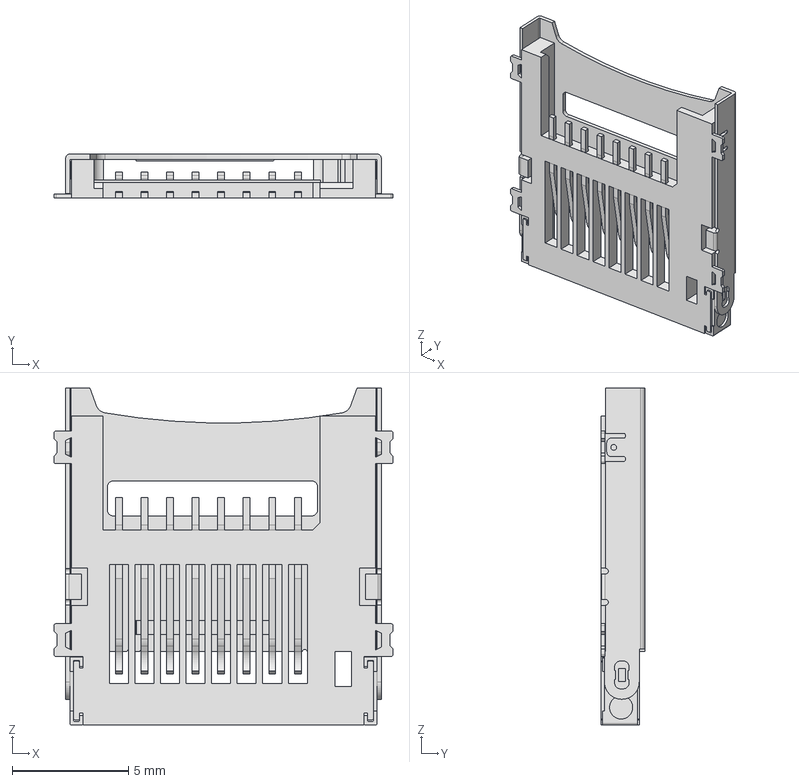
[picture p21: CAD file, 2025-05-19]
HW_design/DEV_V0/CAD Models/0472192001.stp
14.6 x 1.90 x 14.5 mm

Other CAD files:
HW_design/DEV_V0/CAD Models/0878980624.stp

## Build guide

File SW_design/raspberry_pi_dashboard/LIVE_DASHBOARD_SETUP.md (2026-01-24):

# Live ESP32 Dashboard Setup Guide

This guide explains how to access and use the **live** Pocket Lab dashboard that connects to real ESP32 sensor data.

## Quick Start

### 1. Make Sure Backend is Running

```bash
cd raspberry_pi_dashboard
source venv/bin/activate
python app.py
```

The server should start on port **8080** and display:
```
* Running on http://0.0.0.0:8080
UDP listener started on port 5000
```

### 2. Access the Dashboard

**Mockup (for testing UI):**
- URL: `http://192.168.10.2:8080/pocket-lab-mockup.html`
- Uses simulated data at 1 Hz
- No ESP32 required

**Live Dashboard (real ESP32 data):**
- URL: `http://192.168.10.2:8080/pocket-lab-live.html`
- Connects to real ESP32 devices
- Requires ESP32 sending UDP packets

## ESP32 Setup

### UDP Packet Format

Your ESP32 must send JSON packets to the Raspberry Pi on **UDP port 5000**.

**Example JSON packet:**
```json
{
  "node_id": "ESP32_LAB_01",
  "timestamp": 1234567,
  "temperature": 23.5,
  "pressure": 101.3,
  "light_intensity": 542.0,
  "accel_x": 0.12,
  "accel_y": -0.05,
  "accel_z": 9.81,
  "accel_norm": 9.82,
  "gyro_x": 0.02,
  "gyro_y": -0.01,
  "gyro_z": 0.00,
  "gyro_norm": 0.02,
  "mag_x": 25.3,
  "mag_y": -12.7,
  "mag_z": 48.9,
  "mag_norm": 56.4,
  "volume_rms": -28.5,
  "spectral_f1": 245,
  "spectral_f2": 312,
  "spectral_f3": 589,
  "spectral_f4": 678,
  "spectral_fz": 456,
  "spectral_fy": 892,
  "spectral_f5": 723,
  "spectral_f6": 567,
  "spectral_fxl": 634,
  "spectral_f7": 421,
  "spectral_f8": 289,
  "spectral_nir": 156,
  "spectral_vis": 4567,
  "spectral_fd": 234
}
```

### Required Fields

- `node_id` (string): Unique identifier for the ESP32 (e.g., "ESP32_LAB_01")
- `timestamp` (int): ESP32 millis() timestamp (optional)

### Sensor Fields (all optional - send what you have)

**Environmental:**
- `temperature` (float): Temperature in °C
- `pressure` (float): Pressure in kPa
- `light_intensity` (float): Ambient light in lux

**IMU - Accelerometer:**
- `accel_x`, `accel_y`, `accel_z` (float): m/s²
- `accel_norm` (float): Magnitude

**IMU - Gyroscope:**
- `gyro_x`, `gyro_y`, `gyro_z` (float): deg/s
- `gyro_norm` (float): Magnitude

**IMU - Magnetometer:**
- `mag_x`, `mag_y`, `mag_z` (float): µT
- `mag_norm` (float): Magnitude

**Audio:**
- `volume_rms` (float): RMS volume in dB

**Spectral (AS7343 sensor):**
- `spectral_f1` through `spectral_nir`: 14 spectral channels

### ESP32 Code Example (Arduino)

```cpp
#include <WiFi.h>
#include <WiFiUdp.h>
#include <ArduinoJson.h>

const char* ssid = "PocketLabAP";
const char* password = "your_password";
const char* serverIP = "192.168.10.2";  // Raspberry Pi IP
const int serverPort = 5000;

WiFiUDP udp;

void setup() {
    Serial.begin(115200);

    // Connect to WiFi
    WiFi.begin(ssid, password);
    while (WiFi.status() != WL_CONNECTED) {
        delay(500);
        Serial.print(".");
    }
    Serial.println("WiFi connected!");
}

void loop() {
    // Create JSON packet
    StaticJsonDocument<512> doc;
    doc["node_id"] = "ESP32_LAB_01";
    doc["timestamp"] = millis();

    // Add sensor readings
    doc["temperature"] = readTemperature();
    doc["pressure"] = readPressure();
    doc["light_intensity"] = readAmbientLight();
    // ... add more sensor data ...

    // Serialize and send
    char buffer[512];
    serializeJson(doc, buffer);

    udp.beginPacket(serverIP, serverPort);
    udp.write((uint8_t*)buffer, strlen(buffer));
    udp.endPacket();

    // Send at 25-50 Hz (20-40ms delay)
    delay(40);
}
```

## Dashboard Features

### Device Selection

1. **Automatic Discovery**: Devices appear automatically when they send data
2. **Active Status**: Shows which devices are currently sending data (< 5s ago)
3. **Last Seen**: Displays time since last data packet

### Measurement Types

Click measurement cards to add visualizations:

1. **Time-graph**: Rolling time-series chart (5s to 5min windows)
2. **Numeric Only**: Current value display
3. **Numeric w. Statistics**: Min, Max, Avg, StdDev with reset
4. **Vector** (for IMU data): 3D visualization with component breakdown
5. **Electromagnetic Spectrum**: Bar chart of 14 spectral channels

### WebSocket Connection

The dashboard uses **Socket.IO** for real-time updates:
- Connects automatically on page load
- Subscribes to sensor_data for selected device
- Updates displays in real-time as data arrives
- Reconnects automatically if connection drops

## Troubleshooting

### "No active devices found"

**Check:**
1. ESP32 is powered on and connected to WiFi
2. ESP32 is sending UDP packets to correct IP (192.168.10.2) and port (5000)
3. Backend server is running
4. Check debug console at bottom of page for errors

**Test UDP reception manually:**
```bash
# On Raspberry Pi
sudo tcpdump -i wlan0 -n udp port 5000
```

You should see packets from your ESP32 IP address.

### "WebSocket connection error"

**Check:**
1. Backend server is running (Flask + Socket.IO)
2. No firewall blocking port 8080
3. Browser console (F12) for detailed errors

### Charts not updating

**Check:**
1. Debug console shows "Received data from [node_id]"
2. Selected device matches the node_id in ESP32 packets
3. Sensor fields in ESP32 match expected field names
4. Check browser console for JavaScript errors

### ESP32 not connecting to WiFi

**Check:**
1. SSID and password are correct
2. Raspberry Pi AP is running
3. ESP32 is in range
4. Check ESP32 serial monitor for connection status

## Advanced Configuration

### Change UDP Port

Edit `config.py`:
```python
UDP_PORT = 5000  # Change to your port
```

Then restart backend and update ESP32 code.

### Adjust Activity Timeout

Edit `config.py`:
```python
ACTIVITY_TIMEOUT_SECONDS = 5  # Devices inactive after 5s
```

### Custom Node IDs

Use meaningful node IDs in ESP32 code:
```cpp
doc["node_id"] = "CLASSROOM_A_SENSOR_1";
```

The dashboard will display this as the device name.

## Data Flow Diagram

```
ESP32 Sensor
    |
    | UDP JSON packets (25-50 Hz)
    | Port 5000
    v
Raspberry Pi (app.py)
    |
    ├──> SQLite Database (historical data)
    |
    └──> Socket.IO Broadcast
            |
            | WebSocket
            | Real-time updates
            v
        Web Browser
        (pocket-lab-live.html)
            |
            └──> Live Charts & Displays
```

## Database

All sensor data is stored in SQLite at:
```
raspberry_pi_dashboard/instance/dashboard.db
```

**Retention:** Data older than 24 hours is automatically cleaned up.

**Query data:**
```bash
cd raspberry_pi_dashboard
sqlite3 instance/dashboard.db

SELECT * FROM sensor_data WHERE node_id = 'ESP32_LAB_01' ORDER BY timestamp DESC LIMIT 10;
```

## API Endpoints

### GET /api/devices
Returns list of active devices.

**Example:**
```bash
curl http://192.168.10.2:8080/api/devices
```

**Response:**
```json
[
  {
    "node_id": "ESP32_LAB_01",
    "hostname": "ESP32_LAB_01",
    "ip_address": "192.168.10.11",
    "last_seen": "2025-11-02T14:30:45.123456",
    "is_active": true
  }
]
```

### GET /api/devices/<node_id>/sensor-data
Returns recent sensor data for a specific device.

**Parameters:**
- `limit`: Number of records (default: 100)
- `hours`: Time window in hours (default: 1)

**Example:**
```bash
curl "http://192.168.10.2:8080/api/devices/ESP32_LAB_01/sensor-data?limit=10"
```

## Performance

- **UDP Packet Rate:** 25-50 Hz (ESP32)
- **WebSocket Broadcast:** Real-time (< 10ms latency)
- **Chart Update Rate:** 1 Hz (every second)
- **Database Writes:** Every packet
- **Frontend:** No significant CPU load with modern browser

## Support

For issues or questions:
1. Check debug console at bottom of page
2. Check browser console (F12 → Console tab)
3. Check Flask server logs
4. Verify ESP32 serial monitor output

---

**Developed by the Bucharest Applied STEAM Museum**

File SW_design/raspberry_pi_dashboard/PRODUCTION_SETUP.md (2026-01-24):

# Production Deployment Guide

This guide explains how to deploy the Pocket Lab Dashboard in production mode on your Raspberry Pi.

## Quick Start

Run the automated setup script:

```bash
cd ~/BASM_Pocket_Museum/SW_design/raspberry_pi_dashboard
./setup_production.sh
```

This script will:
1. Install Nginx and Avahi (mDNS)
2. Set up Python virtual environment with Gunicorn
3. Configure the hostname to `pocketlab`
4. Set up Nginx reverse proxy (port 80 → 8080)
5. Create and enable the systemd service for auto-start

After setup, reboot your Raspberry Pi:
```bash
sudo reboot
```

## Student-Friendly URLs

Students can access the dashboard using any of these URLs:

- **`http://pocketlab.local`** ✅ Recommended (works on all devices)
- **`http://pocketlab`** (works on most devices)
- **`http://192.168.10.2`** (fallback if mDNS doesn't work)

All URLs automatically redirect to the live dashboard!

## Production Architecture

```
Student Browser
    ↓
http://pocketlab.local (port 80)
    ↓
Nginx (reverse proxy)
    ↓
Gunicorn WSGI Server (port 8080)
    ↓
Flask Application + SocketIO
    ↓
SQLite Database
```

## Manual Setup (if needed)

If you prefer to set up manually or need to troubleshoot:

### 1. Install Dependencies

```bash
sudo apt-get update
sudo apt-get install -y nginx avahi-daemon python3-pip python3-venv
```

### 2. Set Up Python Environment

```bash
cd ~/BASM_Pocket_Museum/SW_design/raspberry_pi_dashboard
python3 -m venv venv
source venv/bin/activate
pip install gunicorn eventlet flask flask-cors flask-socketio python-socketio sqlalchemy
```

### 3. Configure Hostname

```bash
sudo hostnamectl set-hostname pocketlab
sudo nano /etc/hosts
# Add line: 127.0.1.1    pocketlab
```

### 4. Set Up Nginx

```bash
sudo cp nginx_pocketlab.conf /etc/nginx/sites-available/pocketlab
sudo ln -s /etc/nginx/sites-available/pocketlab /etc/nginx/sites-enabled/
sudo rm /etc/nginx/sites-enabled/default
sudo nginx -t
sudo systemctl restart nginx
```

### 5. Set Up Systemd Service

```bash
sudo cp pocketlab.service /etc/systemd/system/
sudo systemctl daemon-reload
sudo systemctl enable pocketlab.service
sudo systemctl start pocketlab.service
```

## Service Management

### Check Status
```bash
sudo systemctl status pocketlab
```

### View Live Logs
```bash
sudo journalctl -u pocketlab -f
```

### Restart Service
```bash
sudo systemctl restart pocketlab
```

### Stop Service
```bash
sudo systemctl stop pocketlab
```

### Start Service
```bash
sudo systemctl start pocketlab
```

## Troubleshooting

### Service won't start
```bash
# Check logs
sudo journalctl -u pocketlab -n 50 --no-pager

# Check if port 8080 is in use
sudo netstat -tulpn | grep 8080

# Test Gunicorn manually
cd ~/BASM_Pocket_Museum/SW_design/raspberry_pi_dashboard
source venv/bin/activate
gunicorn --config gunicorn_config.py app:app
```

### mDNS not working (pocketlab.local doesn't resolve)

```bash
# Restart Avahi
sudo systemctl restart avahi-daemon

# Check Avahi status
sudo systemctl status avahi-daemon

# Test from another device
ping pocketlab.local
```

### Nginx errors

```bash
# Check Nginx configuration
sudo nginx -t

# View Nginx logs
sudo tail -f /var/log/nginx/error.log
```

### Can't access from student devices

1. Make sure all devices are on the same WiFi network
2. Check Raspberry Pi IP: `hostname -I`
3. Try accessing by IP directly: `http://192.168.10.2`
4. Check firewall: `sudo ufw status` (should be inactive or allow port 80)

## Performance Tuning

### For Raspberry Pi 4 (4GB+ RAM)

Edit `/etc/systemd/system/pocketlab.service`:
```ini
Environment="WEB_CONCURRENCY=4"  # More workers
```

### For Raspberry Pi 3/Zero

Keep default settings (3 workers) or reduce to 2 if experiencing issues.

## Security Notes

- The dashboard runs on the local network only (192.168.10.x)
- No external internet access required or configured
- No HTTPS (not needed for local classroom use)
- To add HTTPS, uncomment the SSL section in `nginx_pocketlab.conf` and obtain certificates

## Reverting to Development Mode

To go back to development mode:

```bash
# Stop production service
sudo systemctl stop pocketlab
sudo systemctl disable pocketlab

# Run development server
cd ~/BASM_Pocket_Museum/SW_design/raspberry_pi_dashboard
source venv/bin/activate
python app.py
```

## Updating the Application

When you pull new code:

```bash
cd ~/BASM_Pocket_Museum/SW_design/raspberry_pi_dashboard
git pull
sudo systemctl restart pocketlab
```

## Logs Location

- Application logs: `/var/log/pocketlab/`
- Nginx access logs: `/var/log/nginx/pocketlab_access.log`
- Nginx error logs: `/var/log/nginx/pocketlab_error.log`
- Systemd journal: `journalctl -u pocketlab`

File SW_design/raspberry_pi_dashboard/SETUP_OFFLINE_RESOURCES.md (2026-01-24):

# Setup Offline Resources for Raspberry Pi Dashboard

The Raspberry Pi dashboard requires Chart.js and Bootstrap Icons to function properly. Since the Pi may not have internet access when running as an access point, you need to download these files locally.

## Quick Setup (On a computer with internet access)

### Option 1: Download Script (Linux/Mac)

Run this script on a computer with internet access, then transfer the files to your Raspberry Pi:

```bash
#!/bin/bash
cd raspberry_pi_dashboard/static

# Create directories if they don't exist
mkdir -p js
mkdir -p css
mkdir -p fonts

# Download Chart.js
echo "Downloading Chart.js..."
curl -o js/chart.min.js https://cdn.jsdelivr.net/npm/chart.js@4.4.0/dist/chart.umd.min.js

# Download Socket.IO
echo "Downloading Socket.IO..."
curl -o js/socket.io.min.js https://cdn.socket.io/4.5.4/socket.io.min.js

# Download Bootstrap Icons CSS
echo "Downloading Bootstrap Icons CSS..."
curl -o css/bootstrap-icons.min.css https://cdn.jsdelivr.net/npm/bootstrap-icons@1.11.0/font/bootstrap-icons.min.css

# Download Bootstrap Icons fonts
echo "Downloading Bootstrap Icons fonts..."
curl -o fonts/bootstrap-icons.woff https://cdn.jsdelivr.net/npm/bootstrap-icons@1.11.0/font/fonts/bootstrap-icons.woff
curl -o fonts/bootstrap-icons.woff2 https://cdn.jsdelivr.net/npm/bootstrap-icons@1.11.0/font/fonts/bootstrap-icons.woff2

echo "Done! Now transfer the 'static' folder to your Raspberry Pi."
```

### Option 2: Manual Download (Windows/any browser)

1. **Download Chart.js:**
   - Visit: https://cdn.jsdelivr.net/npm/chart.js@4.4.0/dist/chart.umd.min.js
   - Right-click → Save As → `chart.min.js`
   - Place in: `raspberry_pi_dashboard/static/js/chart.min.js`

2. **Download Socket.IO:**
   - Visit: https://cdn.socket.io/4.5.4/socket.io.min.js
   - Right-click → Save As → `socket.io.min.js`
   - Place in: `raspberry_pi_dashboard/static/js/socket.io.min.js`

3. **Download Bootstrap Icons CSS:**
   - Visit: https://cdn.jsdelivr.net/npm/bootstrap-icons@1.11.0/font/bootstrap-icons.min.css
   - Right-click → Save As → `bootstrap-icons.min.css`
   - Place in: `raspberry_pi_dashboard/static/css/bootstrap-icons.min.css`

4. **Download Bootstrap Icons Fonts:**
   - Visit: https://cdn.jsdelivr.net/npm/bootstrap-icons@1.11.0/font/fonts/bootstrap-icons.woff2
   - Right-click → Save As → `bootstrap-icons.woff2`
   - Place in: `raspberry_pi_dashboard/static/fonts/bootstrap-icons.woff2`

   - Visit: https://cdn.jsdelivr.net/npm/bootstrap-icons@1.11.0/font/fonts/bootstrap-icons.woff
   - Right-click → Save As → `bootstrap-icons.woff`
   - Place in: `raspberry_pi_dashboard/static/fonts/bootstrap-icons.woff`

4. **Update Bootstrap Icons CSS:**
   - Open `raspberry_pi_dashboard/static/css/bootstrap-icons.min.css`
   - Find the `@font-face` section
   - Change the font URL from:
     ```css
     url("./fonts/bootstrap-icons.woff2?...")
     ```
     to:
     ```css
     url("/fonts/bootstrap-icons.woff2")
     ```

### Option 3: Transfer from this repository (if you have the files locally)

If you've already cloned this repository on a machine with internet access and want to download the files there:

```bash
# On your local machine (not the Pi)
cd /path/to/BASM_Pocket_Museum
bash raspberry_pi_dashboard/download_offline_resources.sh

# Then sync to Raspberry Pi
rsync -avz raspberry_pi_dashboard/static/ pi@192.168.10.2:/home/pi/BASM_Pocket_Museum/raspberry_pi_dashboard/static/
```

## Verification

After transferring the files, verify they exist on the Raspberry Pi:

```bash
ls -lh raspberry_pi_dashboard/static/js/chart.min.js
ls -lh raspberry_pi_dashboard/static/js/socket.io.min.js
ls -lh raspberry_pi_dashboard/static/css/bootstrap-icons.min.css
ls -lh raspberry_pi_dashboard/static/fonts/bootstrap-icons.woff*
```

Expected output:
```
-rw-r--r-- 1 pi pi 261K Nov 2 14:00 raspberry_pi_dashboard/static/js/chart.min.js
-rw-r--r-- 1 pi pi  59K Nov 2 14:00 raspberry_pi_dashboard/static/js/socket.io.min.js
-rw-r--r-- 1 pi pi  72K Nov 2 14:00 raspberry_pi_dashboard/static/css/bootstrap-icons.min.css
-rw-r--r-- 1 pi pi 124K Nov 2 14:00 raspberry_pi_dashboard/static/fonts/bootstrap-icons.woff2
-rw-r--r-- 1 pi pi 165K Nov 2 14:00 raspberry_pi_dashboard/static/fonts/bootstrap-icons.woff
```

## Testing

1. Restart the Flask server (if running)
2. Navigate to: http://192.168.10.2:8080/pocket-lab-mockup.html
3. Check the debug console (bottom of page) for:
   - ✅ "Chart.js loaded successfully" (green)
   - ✅ "Pocket Lab Mockup loaded successfully" (green)
4. The page should load in under 2 seconds

## Troubleshooting

**Problem:** Still getting "Chart.js not loaded" error

**Solution:**
- Verify the file exists at the correct path
- Check Flask is serving static files correctly
- Open browser console (F12) and check for 404 errors
- Try accessing directly: http://192.168.10.2:8080/js/chart.min.js

**Problem:** Icons not showing (X symbols instead)

**Solution:**
- Check Bootstrap Icons CSS and fonts are downloaded
- Verify font paths in the CSS file point to `/fonts/` (absolute path)
- Clear browser cache

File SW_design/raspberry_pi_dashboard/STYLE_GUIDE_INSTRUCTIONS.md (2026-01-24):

# BASM Dashboard Style Guide - Viewing Instructions

## Quick Start

### Method 1: View Directly (Recommended for Development)

If you already have the Flask application running:

1. **Start the dashboard server:**
   ```bash
   cd /home/user/BASM_Pocket_Museum/raspberry_pi_dashboard
   python3 app.py
   ```

2. **Open your browser and navigate to:**
   ```
   http://localhost:8080/style-guide.html
   ```

3. **Done!** The style guide should now be visible.

---

### Method 2: View Without Running Server (Static HTML)

If you want to view the style guide without running the Flask server:

1. **Navigate to the static directory:**
   ```bash
   cd /home/user/BASM_Pocket_Museum/raspberry_pi_dashboard/static
   ```

2. **Start a simple HTTP server:**
   ```bash
   # Python 3
   python3 -m http.server 8000

   # Or using Python 2
   python -m SimpleHTTPServer 8000
   ```

3. **Open your browser and navigate to:**
   ```
   http://localhost:8000/style-guide.html
   ```

---

### Method 3: Open in Browser (May have limited functionality)

You can also open the file directly, though some features may not work:

1. **Navigate to the file:**
   ```bash
   /home/user/BASM_Pocket_Museum/raspberry_pi_dashboard/static/style-guide.html
   ```

2. **Open in your browser:**
   - Right-click → Open with → Your Browser
   - Or drag and drop into browser window

**Note:** Some external resources (fonts, icons) may not load properly with this method.

---

## What You'll See

The style guide includes the following sections:

### 1. **Color Palette**
   - **Brand Colors:** Your four accent colors
     - Sunshine Yellow (#f8c01c)
     - Ocean Blue (#375f83)
     - Rose Pink (#d782a0)
     - Cardinal Red (#bd2026)
   - **Light Theme Colors:** Background, text, borders
   - **Dark Theme Colors:** Alternative dark mode palette
   - **Interactive:** Click on any hex code to copy it to clipboard!

### 2. **Typography**
   - All heading levels (H1-H6) using Work Sans font
   - Body text variations (large, regular, small, caption)
   - Font weights, sizes, and line heights
   - Shows how text looks in both light and dark themes

### 3. **Text Widths**
   - Demonstrates different content widths:
     - Full Width (100%) - for tables and data displays
     - Wide (80ch) - for technical content
     - Reading Width (70ch) - optimal for articles
     - Comfortable (60ch) - for blog posts
     - Narrow (50ch) - for mobile layouts
   - Each has example text so you can see readability

### 4. **Cards & Border Radius**
   - Six border radius options:
     - None (0px) - sharp corners
     - Small (4px) - subtle rounding
     - Medium (8px) - balanced
     - Large (12px) - soft appearance
     - X-Large (16px) - prominent
     - XX-Large (24px) - bold
   - Card examples using all four brand colors
   - Hover effects and shadows

### 5. **Buttons**
   - **Primary Buttons:** Solid color buttons for each brand color
   - **Outline Buttons:** Transparent with colored borders
   - **Button Sizes:** Small, Medium, Large, Extra Large
   - **Button States:** Normal, Disabled, With Icons
   - All buttons have hover and active states

### 6. **Form Elements**
   - Text inputs
   - Select dropdowns
   - Text areas
   - Checkboxes (for sensor selection)
   - Radio buttons (for display type)
   - All styled consistently with focus states

### 7. **Component Examples**
   - **Device Card:** How ESP32 devices will appear
   - **Question Card:** Student notebook question layout
   - **Sensor Display Card:** Live sensor readings with charts
   - These show real dashboard components in action

---

## Using the Style Guide

### Theme Switcher

Click the **theme toggle button** in the top-right corner to switch between:
- **Light Theme** (default) - White background, dark text
- **Dark Theme** - Dark background, light text

Your preference is saved in browser localStorage and will persist between visits.

### Navigation

- Use the **Table of Contents** at the top to jump to specific sections
- Smooth scrolling is enabled for easy navigation
- All sections are clearly labeled and organized

### Interactive Features

1. **Copy Hex Codes:**
   - Click on any color hex code to copy it to your clipboard
   - The text will briefly change to "Copied!" to confirm

2. **Hover Effects:**
   - Hover over buttons, cards, and interactive elements to see animations
   - All components have smooth transitions

3. **Responsive:**
   - Resize your browser window to see how components adapt
   - Works on desktop, tablet, and mobile sizes

---

## Customization Guide

### Changing Colors

To modify the brand colors, edit `/static/css/style-guide.css`:

```css
:root {
    /* Brand Colors */
    --color-yellow: #f8c01c;  /* Change to your yellow */
    --color-blue: #375f83;    /* Change to your blue */
    --color-pink: #d782a0;    /* Change to your pink */
    --color-red: #bd2026;     /* Change to your red */
}
```

### Changing Border Radius

All border radius values are defined as CSS variables:

```css
:root {
    --radius-none: 0;
    --radius-sm: 4px;     /* Increase for rounder corners */
    --radius-md: 8px;     /* Default for most cards */
    --radius-lg: 12px;    /* For larger components */
    --radius-xl: 16px;    /* Extra rounded */
    --radius-2xl: 24px;   /* Very rounded */
}
```

### Changing Font Sizes

Typography sizes are also variables:

```css
h1 { font-size: 3rem; }      /* 48px */
h2 { font-size: 2.25rem; }   /* 36px */
h3 { font-size: 1.75rem; }   /* 28px */
/* etc. */
```

### Adding New Components

To add a new component example:

1. **Add HTML in** `style-guide.html`:
   ```html
   <div class="your-component-demo">
       <!-- Your component markup -->
   </div>
   ```

2. **Add CSS in** `style-guide.css`:
   ```css
   .your-component-demo {
       /* Your styles */
   }
   ```

3. **Refresh browser** to see changes

---

## Applying Styles to the Dashboard

Once you've reviewed and approved the styles:

1. **Copy CSS variables** from `style-guide.css` to `styles.css`
2. **Use the color variables** in your dashboard components:
   ```css
   .device-card {
       background: var(--bg-primary);
       border: 2px solid var(--color-blue);
       border-radius: var(--radius-md);
   }
   ```
3. **Apply button classes** directly:
   ```html
   <button class="btn btn-primary-yellow">Submit</button>
   ```

---

## Browser Compatibility

The style guide works best in modern browsers:
- ✅ Chrome/Edge (v90+)
- ✅ Firefox (v88+)
- ✅ Safari (v14+)
- ✅ Opera (v76+)

Features used:
- CSS Custom Properties (CSS Variables)
- CSS Grid
- Flexbox
- Modern font loading
- LocalStorage for theme persistence

---

## Troubleshooting

### Fonts Not Loading

If Work Sans font doesn't appear:

1. **Check internet connection** (font loaded from Google Fonts)
2. **Verify the font link** in `style-guide.html`:
   ```html
   <link href="https://fonts.googleapis.com/css2?family=Work+Sans:wght@300;400;500;600;700;800&display=swap" rel="stylesheet">
   ```
3. **Check browser console** for errors (F12 → Console)

### Icons Not Showing

If Bootstrap Icons don't appear:

1. **Check the icon link** in `style-guide.html`:
   ```html
   <link rel="stylesheet" href="https://cdn.jsdelivr.net/npm/bootstrap-icons@1.11.0/font/bootstrap-icons.css">
   ```
2. **Verify internet connection**

### Theme Not Switching

If the theme toggle doesn't work:

1. **Check browser console** for JavaScript errors
2. **Verify** `style-guide.js` is loaded:
   ```html
   <script src="/js/style-guide.js"></script>
   ```
3. **Clear browser cache** and reload

### Styles Look Wrong

If the styling appears broken:

1. **Verify CSS file is loaded:**
   ```html
   <link rel="stylesheet" href="/css/style-guide.css">
   ```
2. **Check browser console** for 404 errors
3. **Clear browser cache** (Ctrl+Shift+R or Cmd+Shift+R)

---

## Next Steps After Review

Once you've reviewed the style guide:

1. **Provide feedback:**
   - Which border radius do you prefer? (recommend: medium 8px or large 12px)
   - Which text width feels best for reading?
   - Do the brand colors look correct?
   - Any adjustments needed for light/dark themes?

2. **Apply to dashboard:**
   - Update `styles.css` with approved variables
   - Implement components using style guide examples
   - Ensure consistency across all tabs

3. **Test on devices:**
   - Desktop browsers
   - Tablets
   - Mobile phones
   - Raspberry Pi display (if applicable)

---

## Contact

If you encounter any issues or have questions:
- Check the troubleshooting section above
- Review browser console for errors (F12 → Console)
- Take a screenshot of any issues for easier debugging

---

## File Locations

For reference, the style guide files are located at:

```
raspberry_pi_dashboard/
├── static/
│   ├── style-guide.html           # Main style guide page
│   ├── css/
│   │   └── style-guide.css        # Style guide styles
│   └── js/
│       └── style-guide.js         # Theme switcher logic
└── STYLE_GUIDE_INSTRUCTIONS.md    # This file
```

---

**Enjoy exploring the BASM Dashboard Style Guide!** 🎨

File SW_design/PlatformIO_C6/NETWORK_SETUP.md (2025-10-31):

# ESP32 Network Configuration Guide

## Overview

This document describes the WiFi networking implementation for the Physics Lab ESP32 sensor nodes. The implementation allows multiple ESP32 nodes to send sensor data over WiFi to a Raspberry Pi server for real-time dashboard display.

## Architecture

```
┌─────────────────────────────────────────────────────────────┐
│                    WiFi Access Point (AP)                   │
│                  (e.g., PhysicsLab_AP)                      │
│                                                             │
│  2.4 GHz: ESP32 Nodes (reliable, longer range)             │
│  5 GHz:   Student devices (higher bandwidth)               │
└─────────────────────────────────────────────────────────────┘
           │                                    │
           │ Static IP                          │ DHCP
           │ 192.168.1.101-110                  │ Dynamic IPs
           │                                    │
    ┌──────▼─────┐                       ┌─────▼──────┐
    │  ESP32 #1  │                       │  Students  │
    │  ESP32 #2  │                       │  (Mobile)  │
    │  ESP32 #n  │                       │  Devices   │
    └────────────┘                       └────────────┘
           │
           │ UDP Port 5000
           │ JSON Data Packets
           │
    ┌──────▼──────────────────────┐
    │   Raspberry Pi 5 Server     │
    │   IP: 192.168.1.10          │
    │   - UDP Listener (Port 5000)│
    │   - Web Server              │
    │   - Dashboard Display       │
    └─────────────────────────────┘
```

## What Was Implemented

### 1. NetworkTask State Machine

A new FreeRTOS task (`NetworkTask`) was added to handle all WiFi connectivity and data transmission. It follows the same architectural pattern as existing tasks (SensorTask, DisplayTask, etc.).

**State Machine States:**
- **BOOT**: Wait for BMS to latch before initializing WiFi
- **INIT**: Initialize WiFi hardware and configure static IP
- **CONNECTING**: Initial 30-second connection attempt with flashing LED
- **CONNECTED**: Successfully connected, sending data at task rate
- **DISCONNECTED**: Connection lost after initial success, retry every 10 seconds
- **NO_NETWORK**: Terminal state if initial connection fails (LED off, no retries)

### 2. Connection Behavior

As per your requirements:
- **On wake-up**: Wait for BMS latching, then try to connect for 30 seconds while flashing LED on pin 15
- **If unsuccessful**: Turn LED off, assume no network available, don't retry
- **If successful**: Keep LED solid on, start sending data
- **If connection lost**: Retry every 10 seconds indefinitely (LED flashing)

### 3. Data Transmission

- Sends the **last frame** from SharedBuffer at TASK_RATE_NETWORK (50 Hz)
- Uses UDP protocol for low-latency, connectionless transmission
- Data formatted as JSON for easy parsing on the server side
- Only includes sensors that have valid data (checked via timestamp-based has*() methods)

### 4. LED Status Indication

- **OFF**: No network available, or initial connection failed
- **FLASHING**: Attempting to connect/reconnect
- **SOLID ON**: Successfully connected and transmitting

## Configuration Guide

### Per-Node Configuration

Each ESP32 node must be configured individually. Edit the file:
```
SW_design/PlatformIO_C6/src/shared_resources/globals.h
```

**Key settings to modify for each node:**

```cpp
// =========== NETWORK CONFIGURATION ===============

// 1. WiFi Credentials (same for all nodes)
#define NETWORK_SSID                "PhysicsLab_AP"      // Your WiFi SSID
#define NETWORK_PASSWORD            "physics2025"        // Your WiFi password

// 2. Node Identification (MUST BE UNIQUE FOR EACH ESP32!)
#define NETWORK_NODE_ID             "ESP32_01"           // Change to ESP32_02, ESP32_03, etc.

// 3. Static IP Configuration (MUST BE UNIQUE FOR EACH ESP32!)
#define NETWORK_STATIC_IP           192,168,1,101        // ESP32 #1: .101, ESP32 #2: .102, etc.

// 4. Network Settings (same for all nodes)
#define NETWORK_GATEWAY             192,168,1,1          // Your router/AP IP
#define NETWORK_SUBNET              255,255,255,0        // Standard subnet mask
#define NETWORK_HOSTNAME            "PhysicsLab-ESP32-01"// Change for each node

// 5. Server Configuration (same for all nodes)
#define SERVER_IP_ADDRESS           192,168,1,10         // Your Raspberry Pi IP
#define SERVER_UDP_PORT             5000                 // UDP port for data

// Note: Data is sent at TASK_RATE_NETWORK (50 Hz, defined in Task Rates section)
```

### Example: Configuring Multiple Nodes

**ESP32 Node #1:**
```cpp
#define NETWORK_NODE_ID             "ESP32_01"
#define NETWORK_STATIC_IP           192,168,1,101
#define NETWORK_HOSTNAME            "PhysicsLab-ESP32-01"
```

**ESP32 Node #2:**
```cpp
#define NETWORK_NODE_ID             "ESP32_02"
#define NETWORK_STATIC_IP           192,168,1,102
#define NETWORK_HOSTNAME            "PhysicsLab-ESP32-02"
```

**ESP32 Node #3:**
```cpp
#define NETWORK_NODE_ID             "ESP32_03"
#define NETWORK_STATIC_IP           192,168,1,103
#define NETWORK_HOSTNAME            "PhysicsLab-ESP32-03"
```

## Data Format

### JSON Packet Structure

Each UDP packet contains a JSON object with the following structure:

```json
{
  "node_id": "ESP32_01",
  "timestamp": 123456,
  "temperature": 23.45,
  "pressure": 101325.00,
  "light_intensity": 5432.10,
  "accel_x": 0.012,
  "accel_y": -0.005,
  "accel_z": 1.003,
  "accel_norm": 1.004,
  "gyro_x": 0.234,
  "gyro_y": -0.123,
  "gyro_z": 0.456,
  "gyro_norm": 0.567,
  "mag_x": 23.4,
  "mag_y": -12.3,
  "mag_z": 45.6,
  "mag_norm": 52.1,
  "volume_rms": -25.3,
  "spectral_f1": 1234,
  "spectral_f2": 2345,
  ... (14 spectral channels if available)
}
```

**Notes:**
- Only sensors with valid data are included in the packet
- `timestamp`: Milliseconds since ESP32 boot (from `millis()`)
- Spectral data only included if AS7343 sensor is detected
- All floating-point values are formatted to 2-3 decimal places

### Sensor Data Fields

| Field | Description | Unit | Source Sensor |
|---|---|---|---|
| `node_id` | ESP32 node identifier | string | Configuration |
| `timestamp` | Time since boot | ms | System |
| `temperature` | Ambient temperature | °C | ICP201XX |
| `pressure` | Atmospheric pressure | Pa | ICP201XX |
| `light_intensity` | Ambient light level | lux | BH1750 |
| `accel_x/y/z` | Linear acceleration | mg | ICM20948 |
| `accel_norm` | Acceleration magnitude | mg | ICM20948 |
| `gyro_x/y/z` | Rotational velocity | deg/s | ICM20948 |
| `gyro_norm` | Gyro magnitude | deg/s | ICM20948 |
| `mag_x/y/z` | Magnetic field | µT | ICM20948 |
| `mag_norm` | Magnetic magnitude | µT | ICM20948 |
| `volume_rms` | Audio level | dB | MICT3902 |
| `spectral_f1-f8` | Spectral channels | ADC counts | AS7343 |
| `spectral_fz/fy/fxl` | Special channels | ADC counts | AS7343 |
| `spectral_nir` | Near-infrared | ADC counts | AS7343 |
| `spectral_vis` | Visible light | ADC counts | AS7343 |
| `spectral_fd` | Flicker detection | ADC counts | AS7343 |

## Building and Flashing

### Prerequisites
- PlatformIO (VSCode extension or CLI)
- ESP32-C6 USB drivers installed

### Build Process
1. Open project in VSCode with PlatformIO extension
2. Select environment: `esp32-c6-devkitm-1`
3. Configure the node (modify `globals.h` as described above)
4. Build: Click "Build" button or run `pio run`
5. Upload: Click "Upload" button or run `pio run --target upload`
6. Monitor: Click "Serial Monitor" or run `pio device monitor`

### Quick Build Commands
```bash
cd SW_design/PlatformIO_C6

# Build only (check for errors)
pio run

# Build and upload to connected ESP32
pio run --target upload

# Monitor serial output
pio device monitor --baud 115200

# Build + Upload + Monitor (all in one)
pio run --target upload && pio device monitor
```

## Troubleshooting

### LED Status Codes

| LED State | Meaning | Action |
|---|---|---|
| Off | No network / Initial connection failed | Check WiFi SSID/password, verify AP is on |
| Flashing (during boot) | Attempting initial connection | Wait up to 30 seconds |
| Flashing (after connected) | Reconnecting after loss | Check AP stability |
| Solid On | Connected and transmitting | Normal operation |

### Common Issues

**1. LED stays off after boot**
- WiFi credentials incorrect
- Access point not powered on
- ESP32 out of range
- Wrong SSID/password in `globals.h`

**2. LED flashing continuously**
- Initial connection succeeded, but now lost
- AP rebooted or became unstable
- ESP32 moved out of range
- Check AP power and coverage

**3. No data received on server**
- Server IP address incorrect in `globals.h`
- Server not listening on UDP port 5000
- Firewall blocking UDP traffic
- Wrong network subnet

**4. Compilation errors**
- Verify all commas in IP address defines (use commas, not dots)
  - Correct: `192,168,1,101`
  - Wrong: `192.168.1.101`

### Debug Output

Enable verbose network debugging in:
```cpp
// SW_design/PlatformIO_C6/src/shared_resources/global_debug.h

#define DEBUG_NETWORK           1  // Enable network state messages
#define DEBUG_NETWORK_PACKETS   1  // Enable packet content logging (very verbose!)
```

Monitor serial output at 115200 baud to see:
- Connection attempts
- State transitions
- Data transmission frequency
- Error messages

## Network Recommendations

### Band Separation (2.4 GHz vs 5 GHz)

As you suggested, it's beneficial to separate traffic:

**2.4 GHz Band (for ESP32 nodes):**
- Longer range
- Better wall penetration
- More reliable for sensors
- ESP32-C6 supports 2.4 GHz

**5 GHz Band (for student devices):**
- Higher bandwidth
- Less interference
- Better for web browsing
- Keeps sensor traffic unaffected

### Access Point Configuration

Recommended AP settings:
- SSID: `PhysicsLab_AP` (or your choice)
- Security: WPA2-PSK or WPA3
- Channel: Auto (or manually select least congested)
- DHCP range: 192.168.1.50-192.168.1.200 (for student devices)
- Reserved IPs: 192.168.1.101-192.168.1.110 (for ESP32 static IPs)
- Server IP: 192.168.1.10 (Raspberry Pi - static, outside DHCP range)

## Performance Characteristics

### Network Task
- Priority: 7 (lowest priority, won't interfere with sensors)
- Stack size: 8192 bytes (larger for WiFi buffers)
- Run rate: 50 Hz (TASK_RATE_NETWORK)
- Data send rate: 50 Hz (same as task rate - sends every iteration)

### Bandwidth Usage
- Approximate packet size: 200-400 bytes (depending on active sensors)
- At 50 Hz: 10-20 KB/s per node
- For 10 nodes: 100-200 KB/s total
- Well within WiFi capacity

### Latency
- UDP provides minimal latency
- Typical round-trip time: 5-20 ms on local network
- No acknowledgment overhead

## Next Steps

Now that the ESP32 networking is implemented, you'll need to:

1. **Raspberry Pi Server** (Python recommended):
   - UDP listener on port 5000
   - JSON parsing
   - Data storage/buffering
   - Web server for dashboard

2. **Web Dashboard** (HTML/JS):
   - Real-time strip charts per node
   - Tab-based navigation (one tab per ESP32)
   - Auto-hide sensors with NaN values
   - WebSocket or Server-Sent Events for live updates

3. **Student Interaction System**:
   - MAC address tracking
   - Name registration on first connection
   - Question/answer system
   - CSV data storage

Would you like me to start on the Raspberry Pi server implementation next?

## File Changes Summary

**New Files Created:**
- `src/network/NetworkTask.h` - Header file with NetworkTask class definition
- `src/network/NetworkTask.cpp` - Implementation of WiFi connectivity and data transmission

**Modified Files:**
- `src/shared_resources/globals.h` - Added network configuration constants
- `src/shared_resources/global_debug.h` - Added network debug flags
- `src/main.cpp` - Integrated NetworkTask into FreeRTOS system

**No Library Dependencies Added:**
- WiFi and WiFiUdp are built-in to ESP32 Arduino framework
- No additional PlatformIO libraries required

## Testing Checklist

Before deploying to the classroom:

- [ ] Configure unique NODE_ID for each ESP32
- [ ] Configure unique static IP for each ESP32
- [ ] Verify AP is powered on and broadcasting
- [ ] Verify Raspberry Pi is on network (192.168.1.10)
- [ ] Test one ESP32 first (LED should go solid)
- [ ] Verify UDP packets received on RPi (use netcat: `nc -ul 5000`)
- [ ] Test with multiple ESP32s simultaneously
- [ ] Verify no packet collisions or data loss
- [ ] Test reconnection behavior (power cycle AP)
- [ ] Verify LED behavior matches specification
- [ ] Test with student devices connected
- [ ] Verify sensor data appears correctly in JSON

## Contact & Support

For questions or issues with this implementation, check:
- Serial monitor output (115200 baud)
- LED status indicators
- Network configuration in `globals.h`
- Debug flags in `global_debug.h`

Happy experimenting! 🔬📡

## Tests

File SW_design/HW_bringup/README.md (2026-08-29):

# Introduction

The Hardware Bringup folder features test campaigns and resources used throughout the development of the Pocket Lab platform. 

---

## LiPo Battery Characterization

The Pocket Lab is powered by a 3.7V LiPo pouch cell. Safe operation of this cell is enabled by a Battery Management IC, the [BQ24040](https://www.ti.com/lit/ds/symlink/bq24040.pdf?ts=1783749675991) chip by Texas Instruments. While the chip reports battery charging / discharging state to the microcontroller via two open-drain outputs, estimating State-of-Charge (SoC) is left up to the user.
For this purpose, the system includes a voltage divider which steps the battery voltage down to the range readable by the ESP32's internal 12-bit ADC, 1.1V.
Finally, after this voltage reading is scaled back up to the battery's voltage, it needs to be translated into a State of Charge value, similar to the fuel gauge on your car, or the battery percentage on your smartphone.

### Goals and Experimental Setup
This test campaign attempted to:
1. Calibrate the ESP32's ADC Voltage readings of ***VBAT_ALW_ON*** against a high-precision instrument
2. Determine the Voltage - State of Charge relationship for the [KRL502340 500 mAh LiPo cell](https://www.alibaba.com/product-detail/High-Quality-502340-500Mah-Electric-Bicycle_1601204689828.html) used on the Pocket Lab EDU V0. 

**The experimental setup and analysis methods are well documented in this [application note](https://www.ti.com/lit/an/sluaaa1/sluaaa1.pdf?ts=1783827079314) by Texas Instruments.**

To measure battery voltage and current, a [Saleae Logic 8](https://www.saleae.com/products/logic-8) was used in conjunction with a 1 Ohm (1%) shunt resistor. The decision to use a logic analyzer (LA) was motivated by the phenomenal [Logic 2 Automation API](https://saleae.github.io/logic2-automation/) which enabled automatic data capture. Raw data was collected through two LA analog channels (YELLOW and GREEN), together with the ESP32's ADC measurement of *VBAT_ALW_ON*.

Two test conditions were considered - with and without the ESP32's WiFi Modem enabled. Then, both tests were run from a fully charged battery (charged by the on-board BQ24040) until the on-board under-voltage lockout monitor (UVLO) (calibrated to trigger when *VBAT_ALW_ON* drops below 2.9V) removed power from the MCU. 

Data captures were made every 10 seconds, for one second, at a sample rate of 50Hz. All resulting 50 samples were averaged to generate one data-point every 10 seconds.

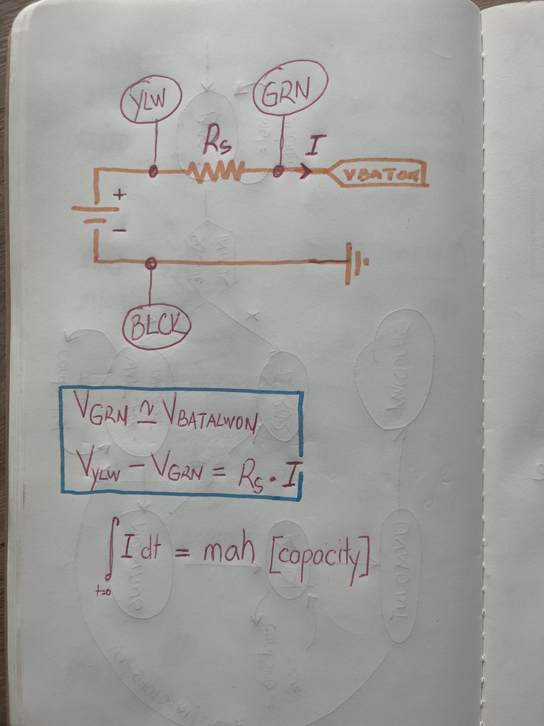
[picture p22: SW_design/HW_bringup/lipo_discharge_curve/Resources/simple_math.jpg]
Physics and Instrumentation Model Used for Measuring Voltage and Current MATH


### Results

1. The ESP32 ADC reliable measures Battery Voltage within 3%.
2. For potentials above 3.6V, the **battery exhibits an almost-linear discharge profile**.
3. Although the rated charged voltage for this battery is 4.2V, the **maximum charge voltage reported across both tests does not exceed 4.06V**. This is likely due to the battery's internal resistance which leads to voltage sag while pulling current, or to a mis-configured battery charging IC which never tops off charge for the LiPo. 
4. While observing sample data collected at a higher rate (10 kHz), large current spikes were observed when the ESP32's WiFi Modem was enabled. In turn, large voltage dips on the *VBAT_ALW_ON* bus, especially toward the lower end of the battery's capacity envelope,  triggered the 2.9V UVLO sooner than in the WiFi-OFF test. This results in **unreliable operation below an average battery voltage of 3.5V when the WiFi Modem is enabled**.
5. Across both discharge tests, **capacities of 437 and 452 mAh respectively were estimated**. This is likely a cumulation between bullet point 2. (see above) and the little capacity left in the battery when the UVLO triggered, thus ending the test. In other words, the HW configuration yields a **usable capacity of approx. 87% for the 500mAh cell**. 

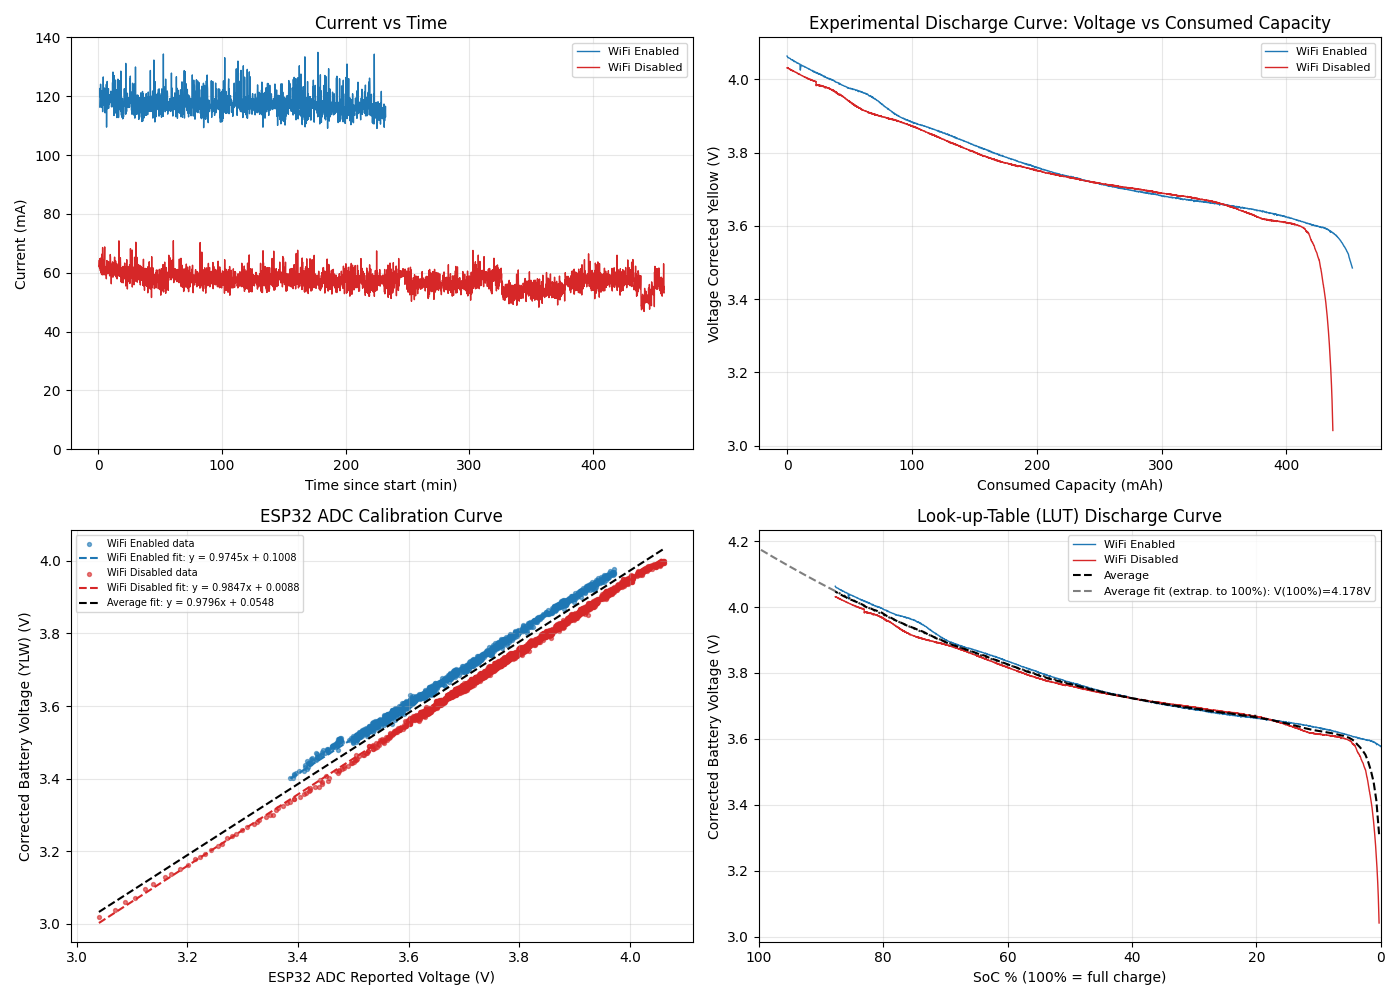
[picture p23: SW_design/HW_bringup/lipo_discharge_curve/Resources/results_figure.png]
Result Figures FIGURES


### Conclusions
1. Battery Voltage is corrected from the ADC's measurement using the formula 
> V_BAT_ADJUSTED = V_ADC_MEASURED * 0.9796 + 0.0548
2. To enable reliable operations with and without WiFi enabled, the **usable Battery Voltage range was limited to 3.6 - 4.2 V**.
3. This range was mapped to a 0 - 100% SoC range and implemented using a look-up table. 
> ESTIMATED_SOC = fn (V_BAT_ADJUSTED)

### Limitations

* This method for determining SoC from Voltage assumes a very low discharge rate, compared to the battery's C rating. In our case, when operating at 120 mA, that represents a 0.24C discharge.

### Resources
* As always, full datasets, and analysis scripts are available inside the ***lipo_discharge_curve*** directory.

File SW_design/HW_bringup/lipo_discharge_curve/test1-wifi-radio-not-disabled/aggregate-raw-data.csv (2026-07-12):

time_since_start(s) | VBAT_ALW_ON | V_YLW | V_GRN
70.145 | 3.972 | 4.09325925925926 | 3.97696296296296
80.165 | 3.964 | 4.09160714285714 | 3.97135714285714
90.185 | 3.971 | 4.0889 | 3.9662
100.205 | 3.969 | 4.0888 | 3.96913333333333
110.225 | 3.972 | 4.08825 | 3.96417857142857
120.245 | 3.967 | 4.08771428571429 | 3.96617857142857
130.265 | 3.97 | 4.08714814814815 | 3.96751851851852
140.285 | 3.967 | 4.08651851851852 | 3.96825925925926
150.305 | 3.972 | 4.08622222222222 | 3.97007407407407
160.325 | 3.968 | 4.0844 | 3.96343333333333
170.345 | 3.969 | 4.0834 | 3.96156666666667
180.365 | 3.966 | 4.08340625 | 3.96421875
190.385 | 3.968 | 4.08303571428572 | 3.96510714285714
200.405 | 3.959 | 4.0816 | 3.95986666666667
210.425 | 3.963 | 4.08253125 | 3.96778125
220.445 | 3.961 | 4.08039285714286 | 3.96046428571428
230.465 | 3.965 | 4.08046666666667 | 3.96213333333333
240.485 | 3.961 | 4.07807142857143 | 3.95153571428571
250.505 | 3.963 | 4.07917857142857 | 3.96132142857143
260.525 | 3.957 | 4.07771875 | 3.955375
270.545 | 3.962 | 4.07785714285714 | 3.95585714285714
280.565 | 3.953 | 4.07751851851852 | 3.96055555555556
290.585 | 3.954 | 4.07622222222222 | 3.95837037037037
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

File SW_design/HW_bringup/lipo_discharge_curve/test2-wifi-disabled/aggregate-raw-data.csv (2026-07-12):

time_since_start(s) | VBAT_ALW_ON | V_YLW | V_GRN
30 | 4.061 | 4.06110714285714 | 3.99885714285714
40 | 4.06 | 4.06166666666667 | 3.99933333333333
50 | 4.058 | 4.06055555555556 | 3.9962962962963
60 | 4.061 | 4.06185714285714 | 4.00028571428571
70 | 4.058 | 4.06007407407407 | 3.99548148148148
80 | 4.058 | 4.0605625 | 3.99578125
90 | 4.062 | 4.05955555555556 | 3.99537037037037
100 | 4.057 | 4.05982142857143 | 3.99914285714286
110 | 4.061 | 4.05875 | 3.99382142857143
120 | 4.06 | 4.05892857142857 | 3.99892857142857
130 | 4.059 | 4.05809375 | 3.99421875
140 | 4.055 | 4.05811111111111 | 3.9952962962963
150 | 4.057 | 4.05743333333333 | 3.99243333333333
160 | 4.058 | 4.05792592592592 | 3.99855555555555
170 | 4.052 | 4.05596296296296 | 3.99285185185185
180 | 4.057 | 4.05693333333333 | 3.99176666666667
190 | 4.055 | 4.05564285714286 | 3.98925
200 | 4.055 | 4.05648148148148 | 3.9967037037037
210 | 4.055 | 4.05548148148148 | 3.98692592592593
220 | 4.055 | 4.05596428571428 | 3.99675
230 | 4.052 | 4.0545 | 3.99014285714286
240 | 4.055 | 4.05457142857143 | 3.99342857142857
250 | 4.054 | 4.05353571428571 | 3.99032142857143
260 | 4.053 | 4.05456666666667 | 3.9949
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

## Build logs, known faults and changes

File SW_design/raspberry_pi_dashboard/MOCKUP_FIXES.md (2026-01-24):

# Mockup Fixes Summary

## Issues to Fix

### 1. Custom SVG Icons
Replace Bootstrap icons with custom SVG icons in yellow squares:

```javascript
const MEASUREMENT_ICONS = {
    temperature: `<svg viewBox="0 0 24 24" fill="currentColor"><path d="M17 4v8a5 5 0 11-10 0V4a3 3 0 116 0zm-5 14a3 3 0 003-3h-6a3 3 0 003 3z"/></svg>`,
    pressure: `<svg viewBox="0 0 24 24" fill="currentColor"><circle cx="12" cy="12" r="9" stroke="currentColor" stroke-width="2" fill="none"/><path d="M12 6v6l4 4"/></svg>`,
    acceleration: `<svg viewBox="0 0 24 24" fill="currentColor"><path d="M4 12h16M4 12l4-4M4 12l4 4M20 12l-4-4M20 12l-4 4"/></svg>`,
    // ... etc
};
```

### 2. Color Definitions
Add color for each measurement type:

```javascript
const MEASUREMENT_COLORS = {
    temperature: '#bd2026',      // RED
    pressure: '#375f83',         // BLUE
    acceleration: '#10b981',     // GREEN (new)
    gyro: '#f97316',            // ORANGE (new)
    magnetometer: '#f8c01c',    // YELLOW
    volume: '#d782a0',          // PINK/MAGENTA
    ambientLight: '#ffffff',    // WHITE
    spectrum: '#8b5cf6'         // PURPLE (for spectrum)
};
```

### 3. Debug Logging
Add debugLog() calls throughout:

```javascript
function initializeChart(displayId, measurementKey, measurement) {
    debugLog(`Initializing chart for ${displayId}...`);

    const canvas = document.getElementById(`${displayId}-chart`);
    if (!canvas) {
        debugLog(`ERROR: Canvas element not found: ${displayId}-chart`, 'error');
        return;
    }

    debugLog(`Canvas found, creating Chart.js instance...`);
    // ... rest of code
}
```

### 4. Chart Initialization Fix
Ensure charts initialize properly:

```javascript
// Wait for canvas to be in DOM before initializing
setTimeout(() => {
    initializeChart(displayId, measurementKey, measurement);
}, 200); // Increased from 100ms
```

## Test Instructions

1. **Reload page** - Check debug console at bottom
2. **Look for**:
   - "Chart.js loaded successfully" (green)
   - "Initializing chart for display-xxx..."
   - Any RED error messages
3. **Open Browser DevTools** (F12) → Console tab
4. **Take screenshot** of both consoles and send to me

## Debugging Steps

If charts still don't show:
1. Check browser console for errors
2. Check if Chart.js CDN is accessible
3. Verify canvas elements are being created
4. Check CSS display properties

## Files to Update

- `static/js/pocket-lab-mockup.js` - Add icons, colors, debug logging
- `static/css/pocket-lab-mockup.css` - Add color classes for measurement cards

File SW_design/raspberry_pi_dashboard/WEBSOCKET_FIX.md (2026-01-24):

# WebSocket Live Data Fix

## Problem

Live sensor data was not displaying on the dashboard. Symptoms:
- Cards showed `--` or nil values
- Backend received UDP packets (confirmed in terminal logs)
- Dashboard responded to ESP32 on/off
- WebSocket connected successfully
- But NO actual sensor readings appeared

## Root Cause

**Event Name Mismatch:**

The frontend was emitting a `'join'` event but the backend was listening for `'subscribe_device'`.

```javascript
// BEFORE (frontend):
AppState.socket.emit('join', { room: 'device_${device.node_id}' });

// Backend was listening for:
@socketio.on('subscribe_device')
def handle_subscribe_device(data):
    node_id = data.get('node_id')
    # ...
    join_room(f'device_{node_id}')
```

**Result:** The client never actually joined the WebSocket room, so it never received the sensor data broadcasts that were being sent to that room.

## The Fix

**Changed frontend to match backend API:**

```javascript
// AFTER (frontend):
AppState.socket.emit('subscribe_device', { node_id: device.node_id });
```

Now when you select a device:
1. Frontend emits `'subscribe_device'` with `{node_id: "192.168.10.11"}`
2. Backend handler receives this and calls `join_room('device_192.168.10.11')`
3. Backend broadcasts sensor data to `room='device_192.168.10.11'`
4. Frontend receives the sensor_data events
5. Displays update with live values!

## Enhanced Debug Logging

Added comprehensive logging to track data flow:

**WebSocket Events:**
- `📡 Subscribing to device...` - When selectDevice() is called
- `✅ Subscription confirmed for...` - Backend confirms room joined
- `📦 Received sensor_data event for...` - Data arrives from WebSocket

**Data Processing:**
- `🔍 handleSensorData called: node_id=...` - Entry point for sensor data
- `📊 Sensor data keys: temperature, pressure, accel_x...` - Fields in packet
- `📊 Processing sensor data for N active displays` - How many displays to update
- `→ temperature: 23.45` - Extracted value for each measurement
- `⚠️ No value extracted for...` - If field is missing

**Display Updates:**
- `🔄 updateDisplay: display-id, temperature, Numeric Only` - Update triggered

## How to Verify the Fix

### 1. Check WebSocket Subscription

Open the live dashboard and watch the debug console (bottom of page):

```
[HH:MM:SS] 🔌 Connecting to WebSocket...
[HH:MM:SS] ✅ WebSocket connected!
[HH:MM:SS] 📡 Subscribing to device 192.168.10.11...
[HH:MM:SS] ✅ Subscription confirmed for 192.168.10.11
```

If you see `❌ Cannot subscribe - WebSocket not connected`, refresh the page.

### 2. Check Data Reception

After selecting a device and adding a measurement display:

```
[HH:MM:SS] 📦 Received sensor_data event for 192.168.10.11
[HH:MM:SS] 🔍 handleSensorData called: node_id=192.168.10.11, selectedDevice=192.168.10.11
[HH:MM:SS] 📊 Sensor data keys: node_id, timestamp, temperature, pressure, accel_x, accel_y, accel_z...
[HH:MM:SS] 📊 Processing sensor data for 1 active displays
[HH:MM:SS]   → temperature: 23.45
[HH:MM:SS] 🔄 updateDisplay: display-temperature-Numeric Only, temperature, Numeric Only
```

### 3. Verify Live Values

The numeric displays should now show:
- **Actual sensor values** (e.g., "23.45 °C")
- **Timestamp** showing when data was received
- **Values updating** as new UDP packets arrive

### 4. Test Multiple Displays

Add several measurements and verify debug console shows:

```
[HH:MM:SS] 📊 Processing sensor data for 3 active displays
[HH:MM:SS]   → temperature: 23.45
[HH:MM:SS]   → pressure: 101.32
[HH:MM:SS]   → acceleration: {"x":0.12,"y":-0.05,"z":9.81,"norm":9.82}
[HH:MM:SS] 🔄 updateDisplay: display-temperature-Numeric Only...
[HH:MM:SS] 🔄 updateDisplay: display-pressure-Time-graph...
[HH:MM:SS] 🔄 updateDisplay: display-acceleration-Vector...
```

## Troubleshooting

### Still seeing `--` or nil values?

**Check debug console for these messages:**

1. **WebSocket not connected:**
   ```
   ❌ Cannot subscribe - WebSocket not connected
   ```
   **Fix:** Refresh the page

2. **Not receiving sensor_data events:**
   - Check if `📦 Received sensor_data event` appears
   - If not, backend may not be broadcasting
   - Check Flask server logs for UDP packet reception

3. **Receiving data but for wrong device:**
   ```
   ⏭️ Skipping data for 192.168.10.12 (selected: 192.168.10.11)
   ```
   **Fix:** This is normal - you're receiving broadcasts for other devices

4. **Missing sensor fields:**
   ```
   ⚠️ No value extracted for temperature
   ```
   **Fix:** ESP32 not sending that field - check ESP32 JSON packet

5. **No active displays:**
   ```
   📊 Processing sensor data for 0 active displays
   ```
   **Fix:** Add some measurement displays by clicking the measurement cards

### Backend not broadcasting?

Check Flask server logs for:

```
INFO - Received data from 192.168.10.11: {...}
INFO - Stored sensor data from 192.168.10.11
```

If you don't see these, the UDP listener isn't receiving packets. Check:
- ESP32 is sending to correct IP (192.168.10.2) and port (5000)
- ESP32 is connected to the AP
- Use `sudo tcpdump -i wlan0 -n udp port 5000` to monitor UDP traffic

## Testing Procedure

1. **Start backend:**
   ```bash
   cd raspberry_pi_dashboard
   source venv/bin/activate
   python app.py
   ```

2. **Power on ESP32**
   - Wait for WiFi connection
   - Should appear in device grid

3. **Open live dashboard:**
   - Navigate to `http://192.168.10.2:8080/pocket-lab-live.html`
   - Watch debug console for WebSocket connection

4. **Select device:**
   - Click on device card (e.g., 192.168.10.11)
   - Debug console should show subscription confirmation

5. **Add measurement displays:**
   - Click "Temperature → Numeric Only"
   - Click "Pressure → Time-graph"
   - Click "Acceleration → Vector"

6. **Verify live data:**
   - Temperature should show actual °C value
   - Pressure chart should plot real-time data
   - Acceleration vector should move with device motion
   - Debug console shows continuous data processing

## Files Changed

**`raspberry_pi_dashboard/static/js/pocket-lab-live.js`:**
- Line 232-239: Added debug logging for sensor_data events and subscription responses
- Line 444-448: Changed `emit('join', {room: ...})` to `emit('subscribe_device', {node_id: ...})`
- Line 251-292: Enhanced handleSensorData() with comprehensive logging
- Line 1024: Added logging to updateDisplay()

**Backend (no changes needed):**
- `app.py` already had the correct `@socketio.on('subscribe_device')` handler
- `udp_listener.py` already broadcasts to the correct room

---

**Fix Status:** COMPLETE

The WebSocket subscription now works correctly. Live sensor data flows from ESP32 → UDP → Backend → WebSocket → Frontend → Displays.

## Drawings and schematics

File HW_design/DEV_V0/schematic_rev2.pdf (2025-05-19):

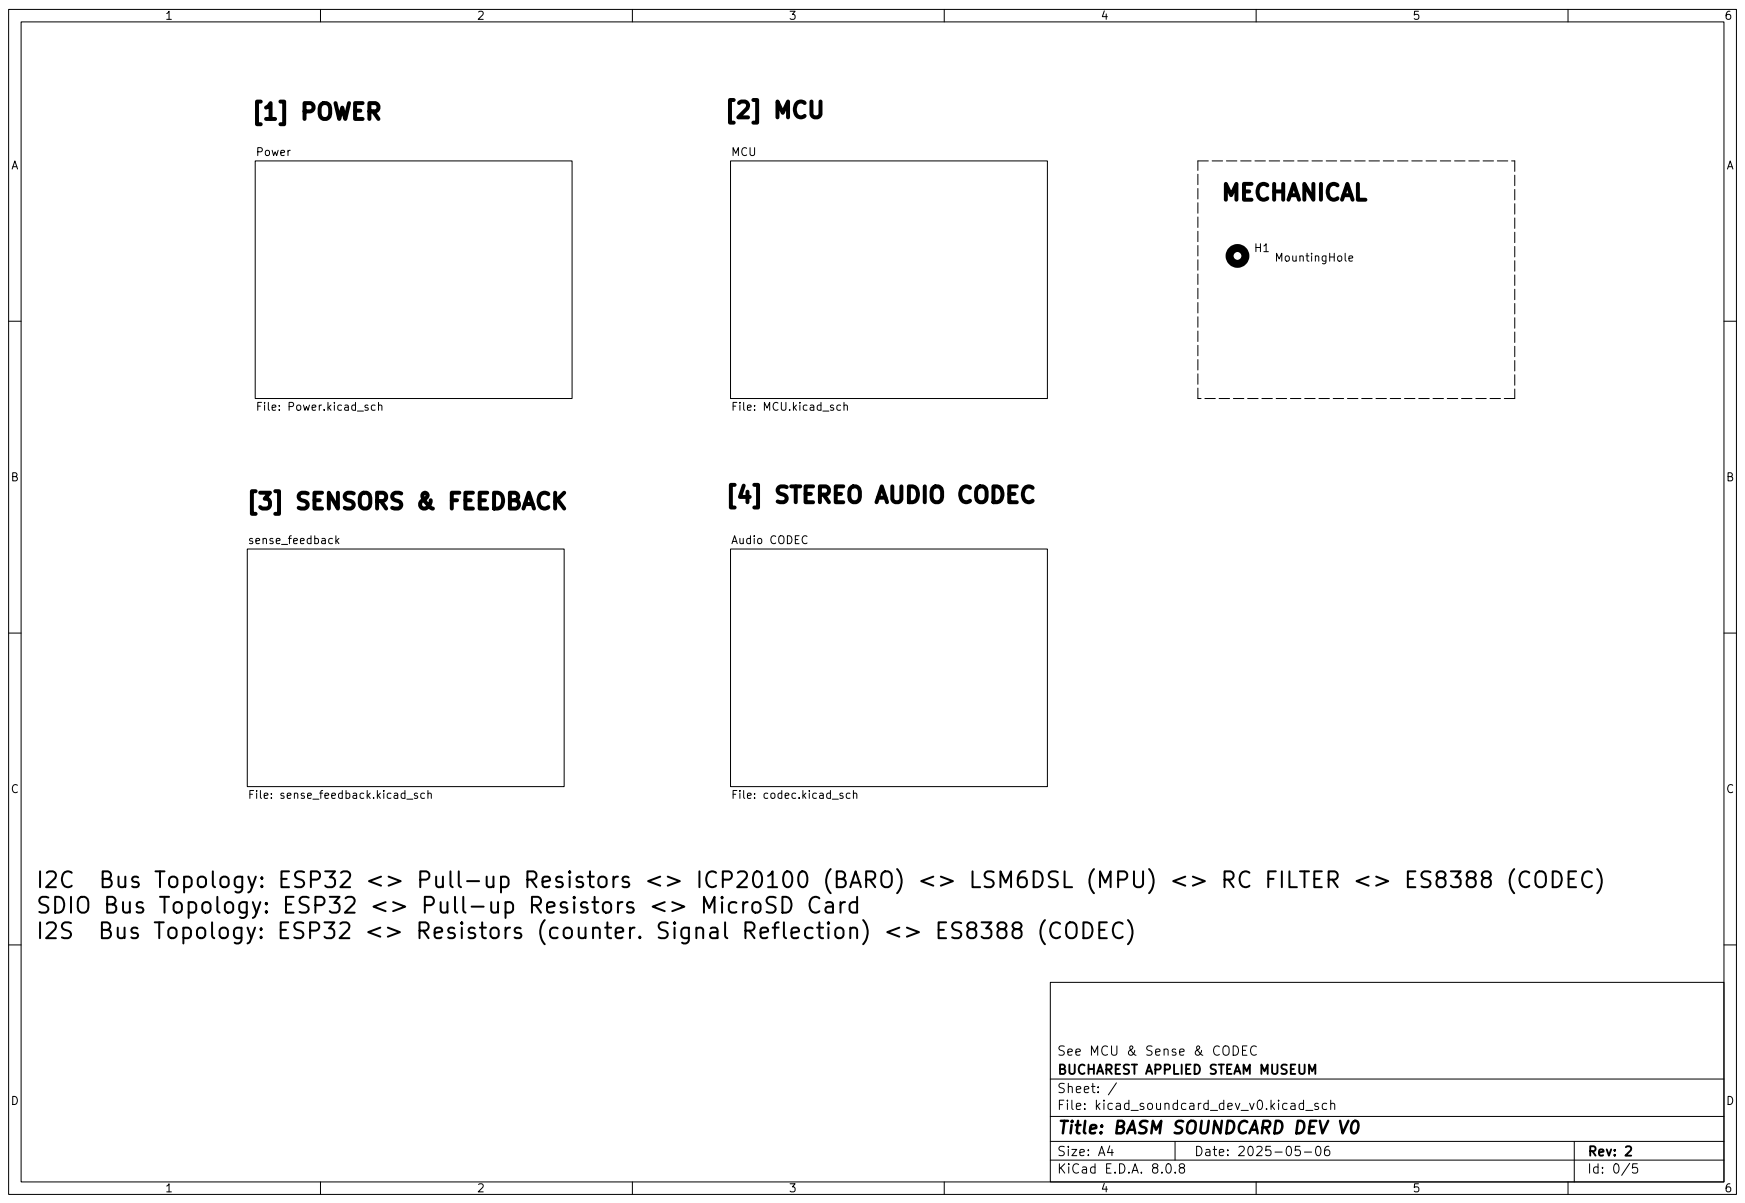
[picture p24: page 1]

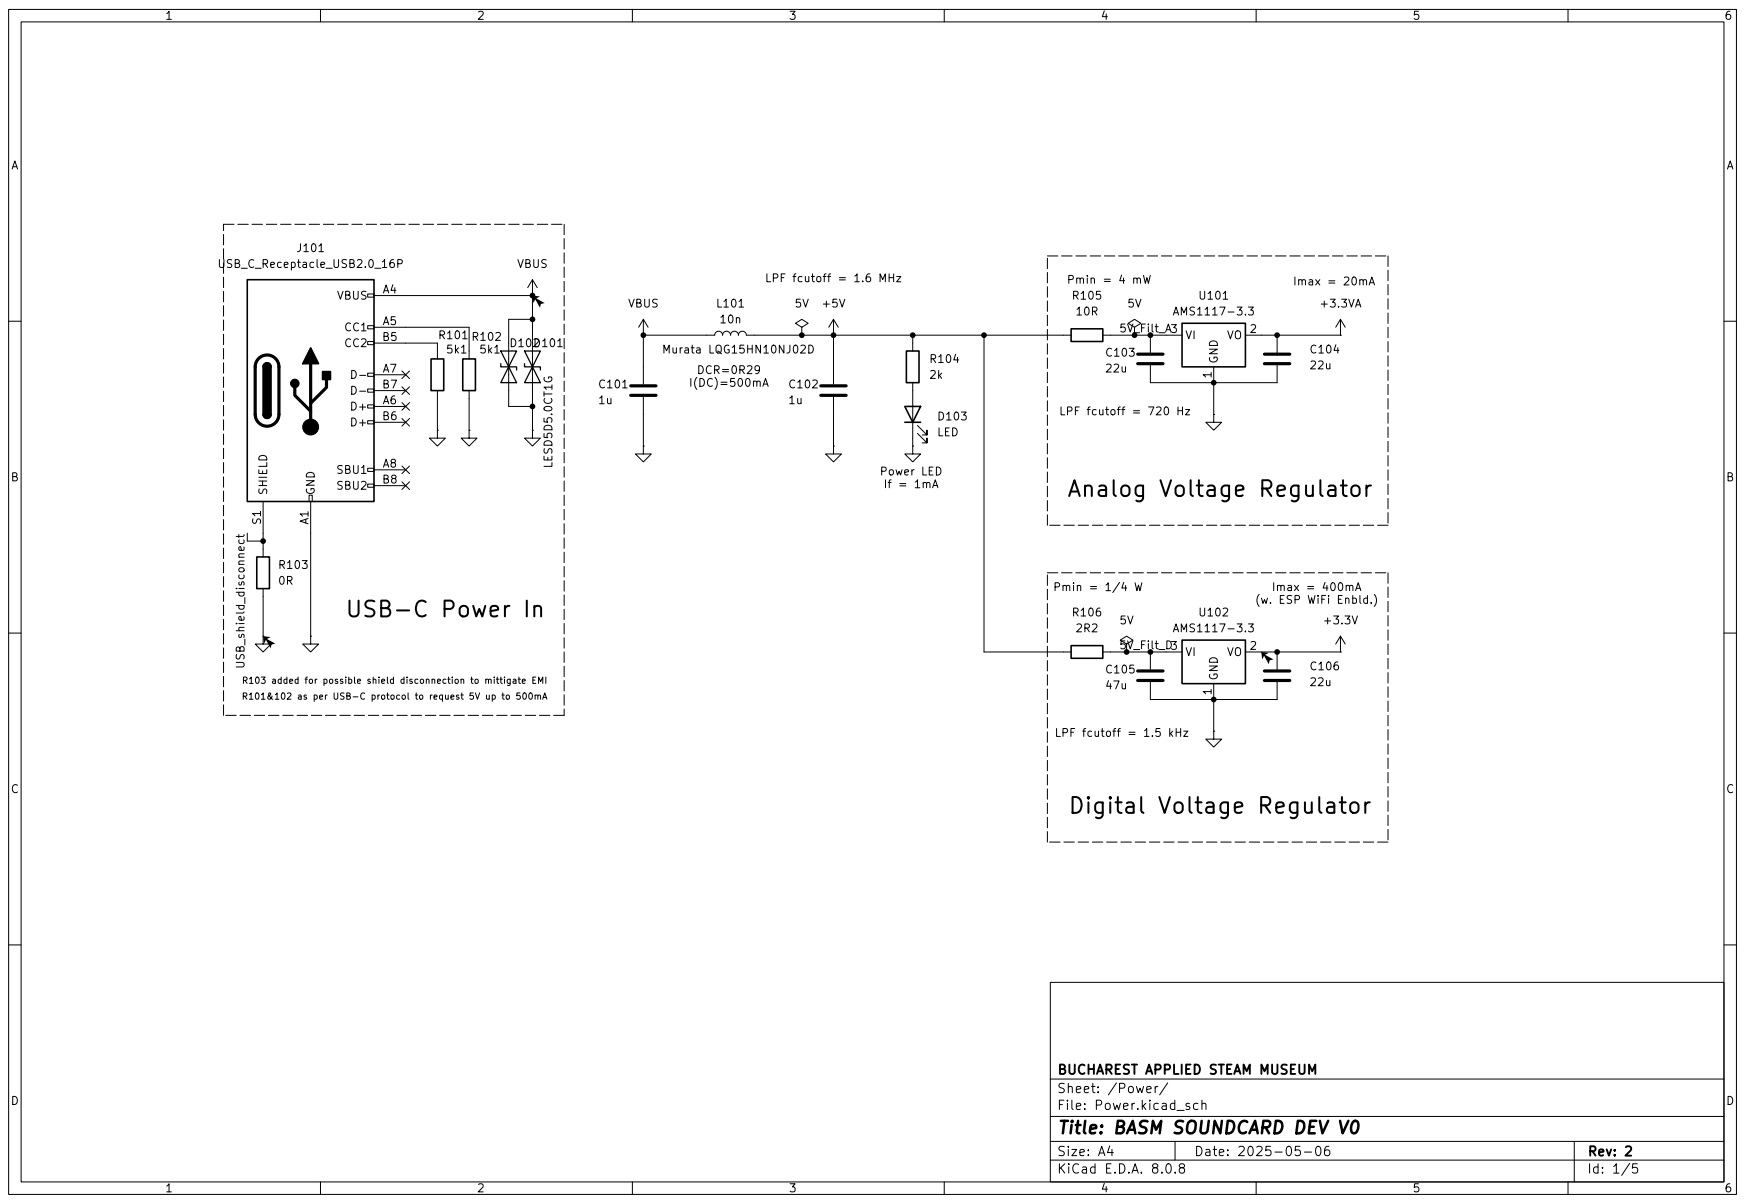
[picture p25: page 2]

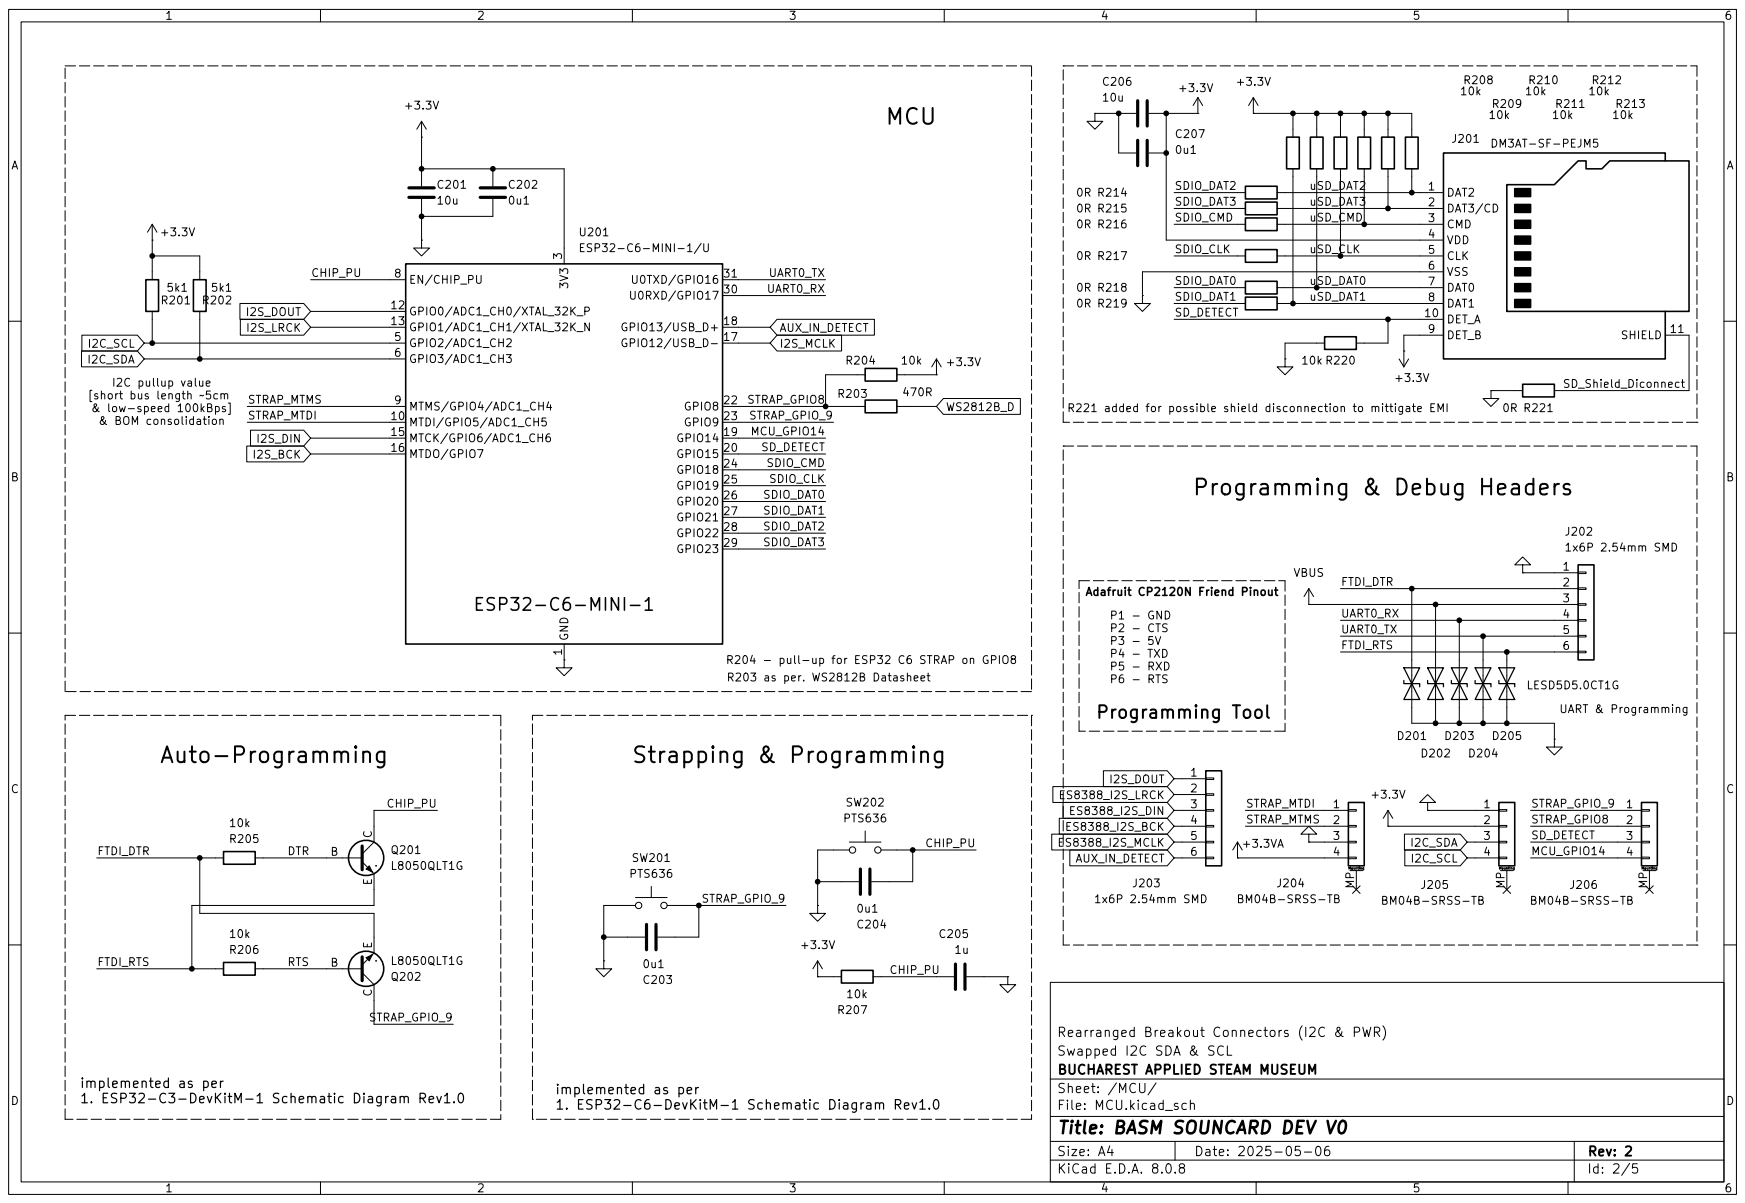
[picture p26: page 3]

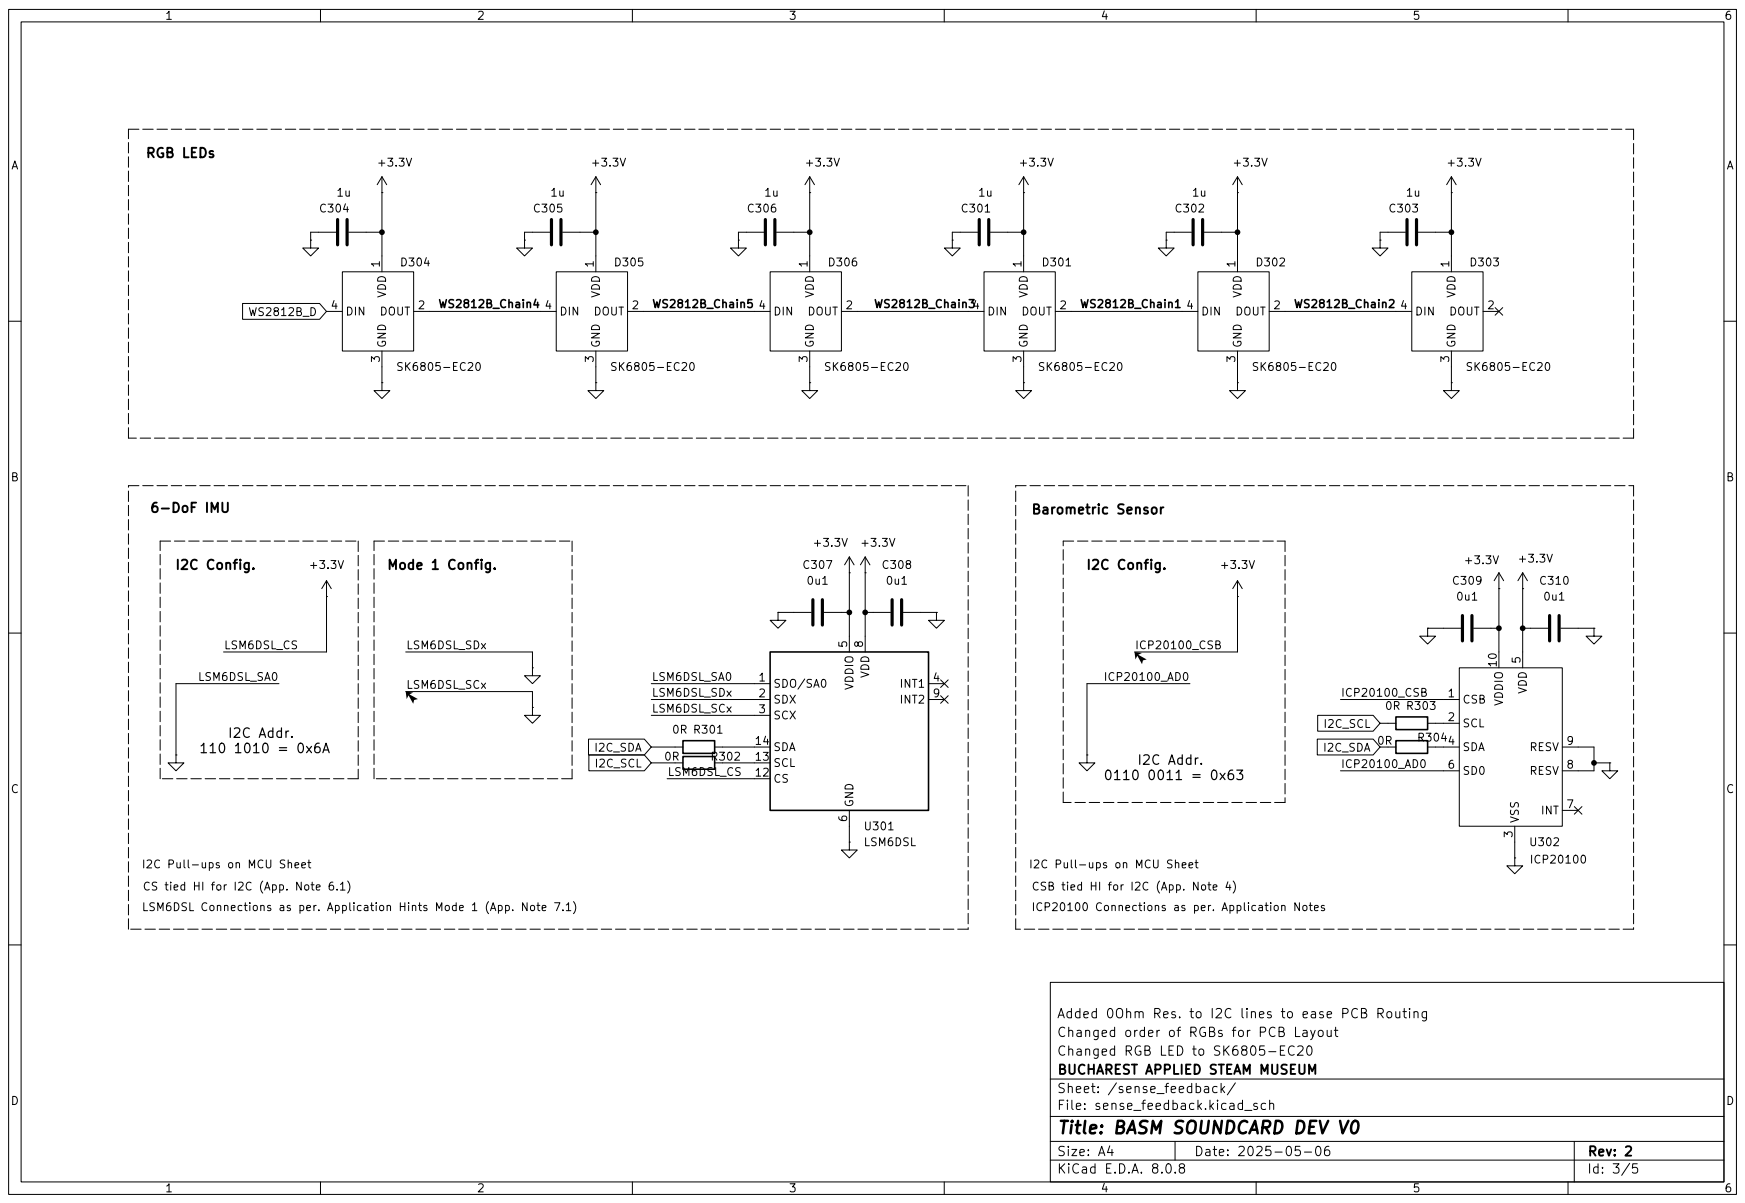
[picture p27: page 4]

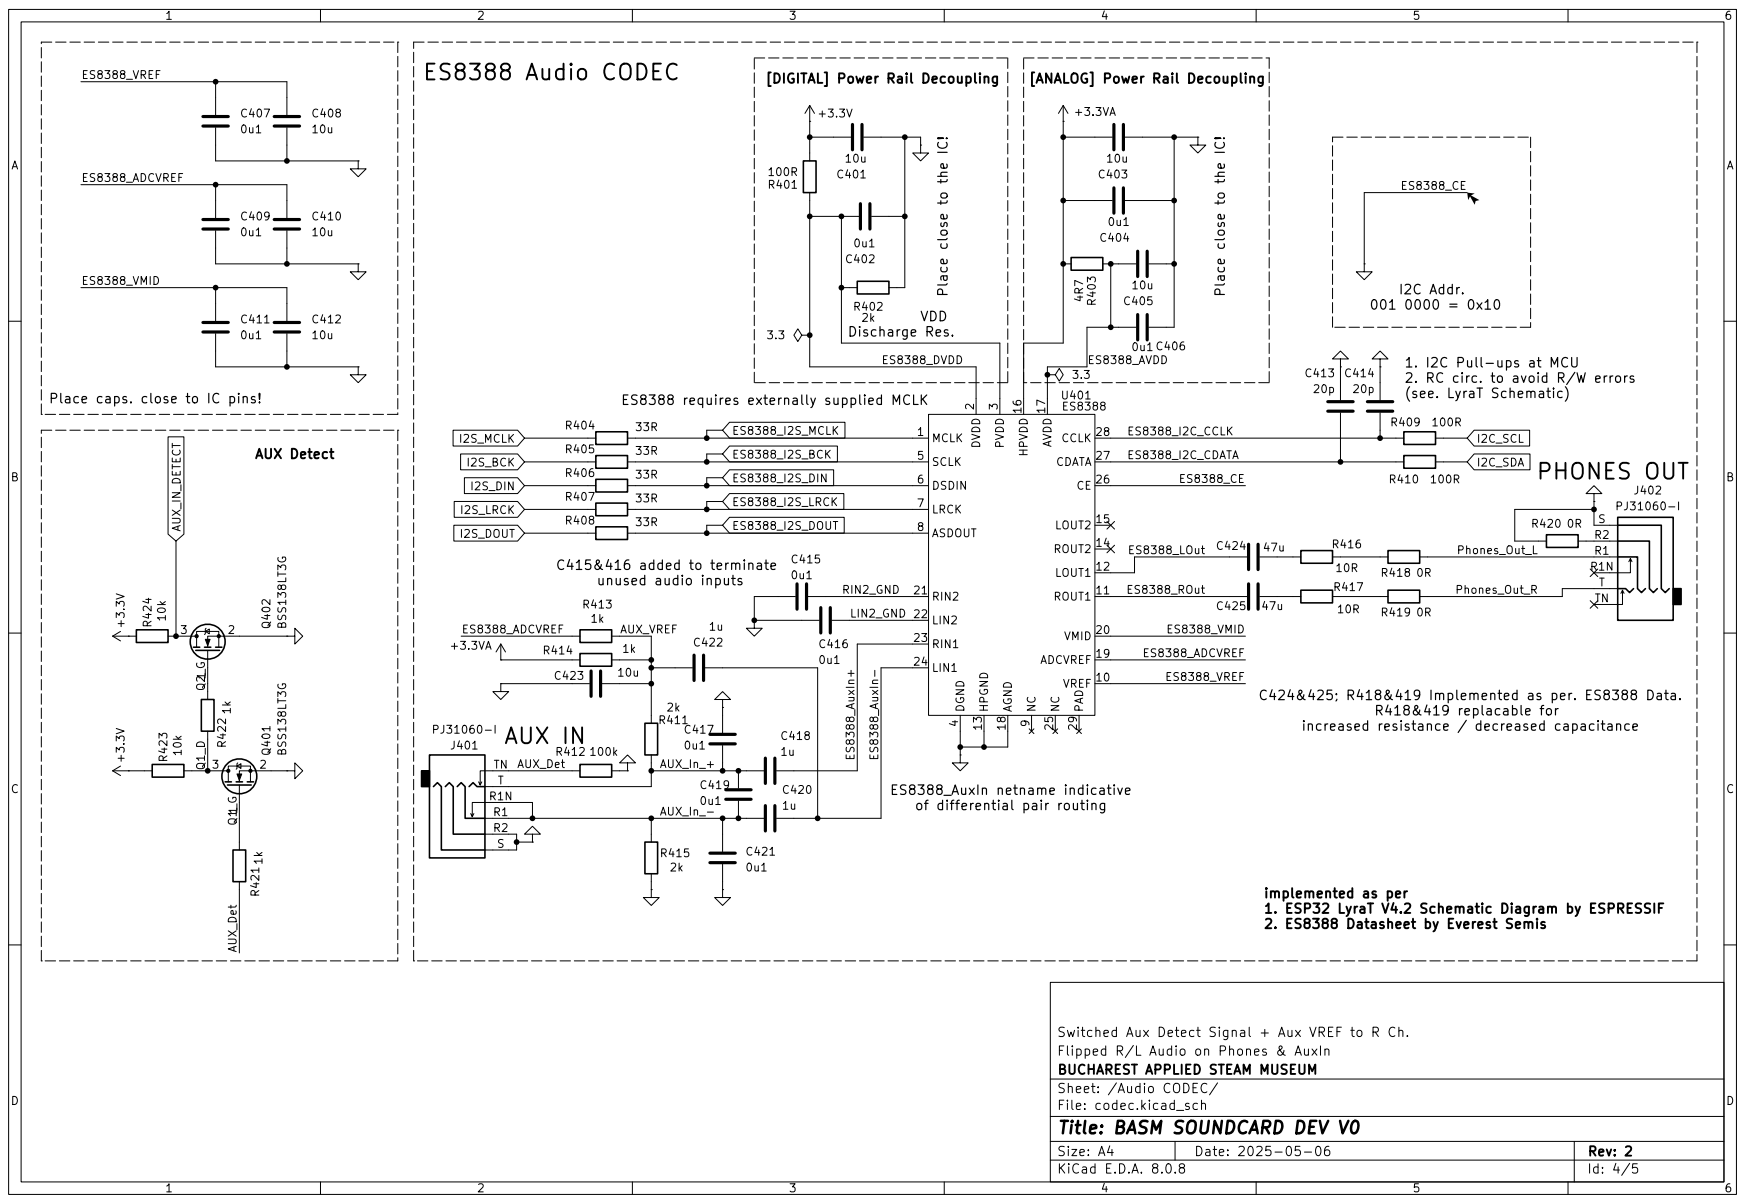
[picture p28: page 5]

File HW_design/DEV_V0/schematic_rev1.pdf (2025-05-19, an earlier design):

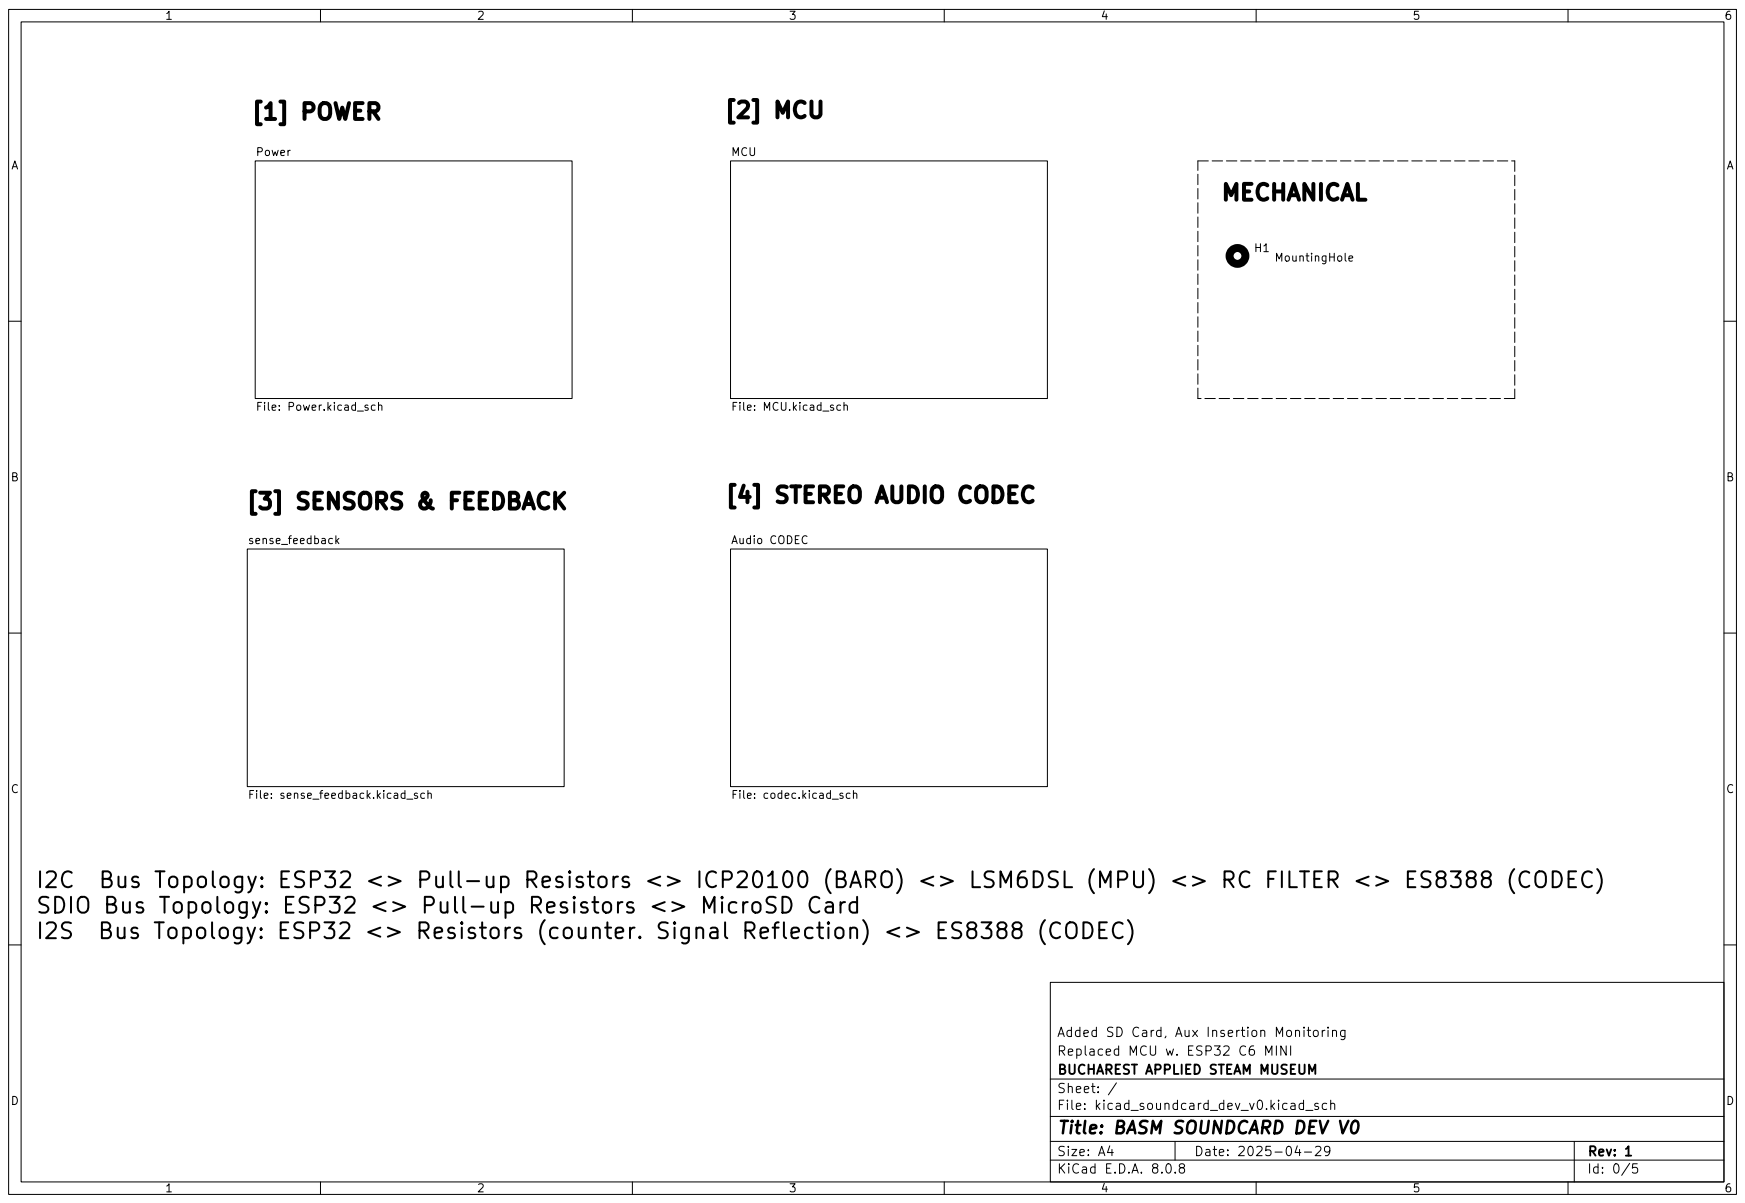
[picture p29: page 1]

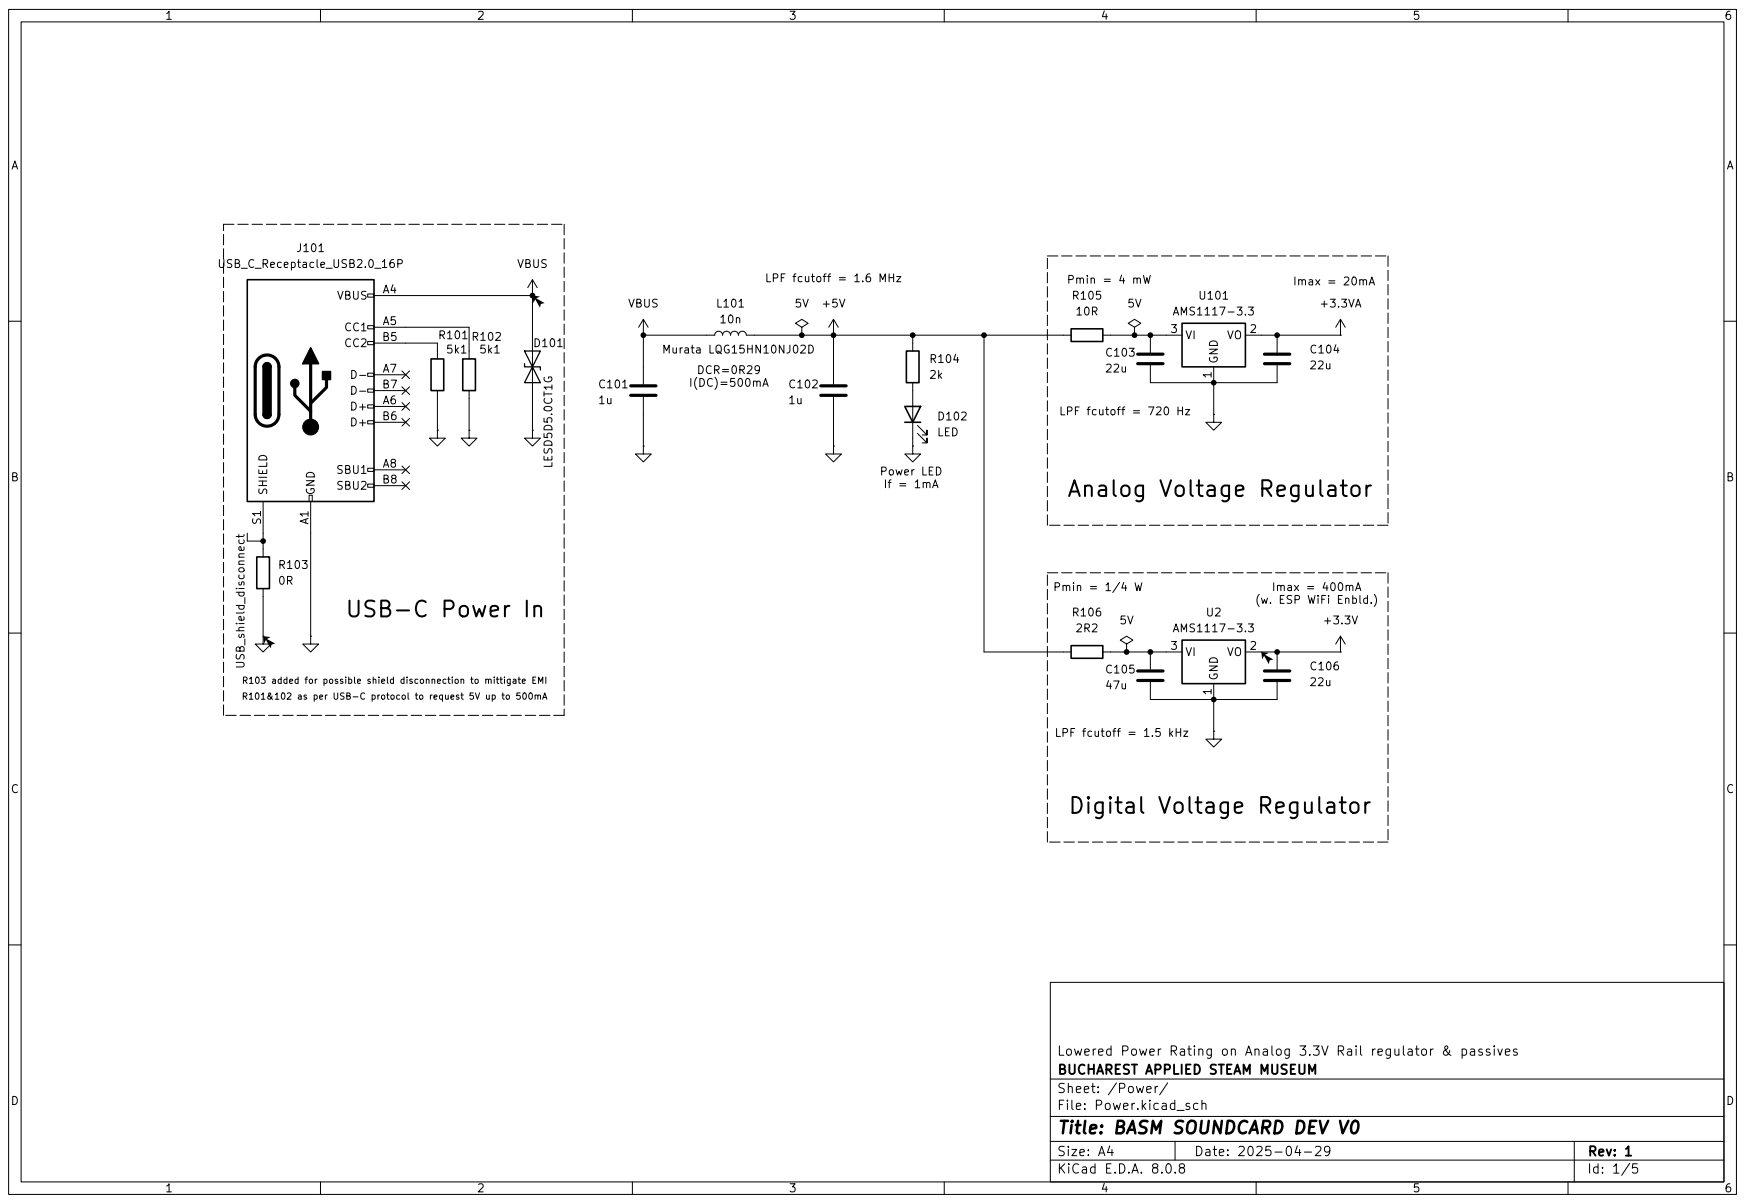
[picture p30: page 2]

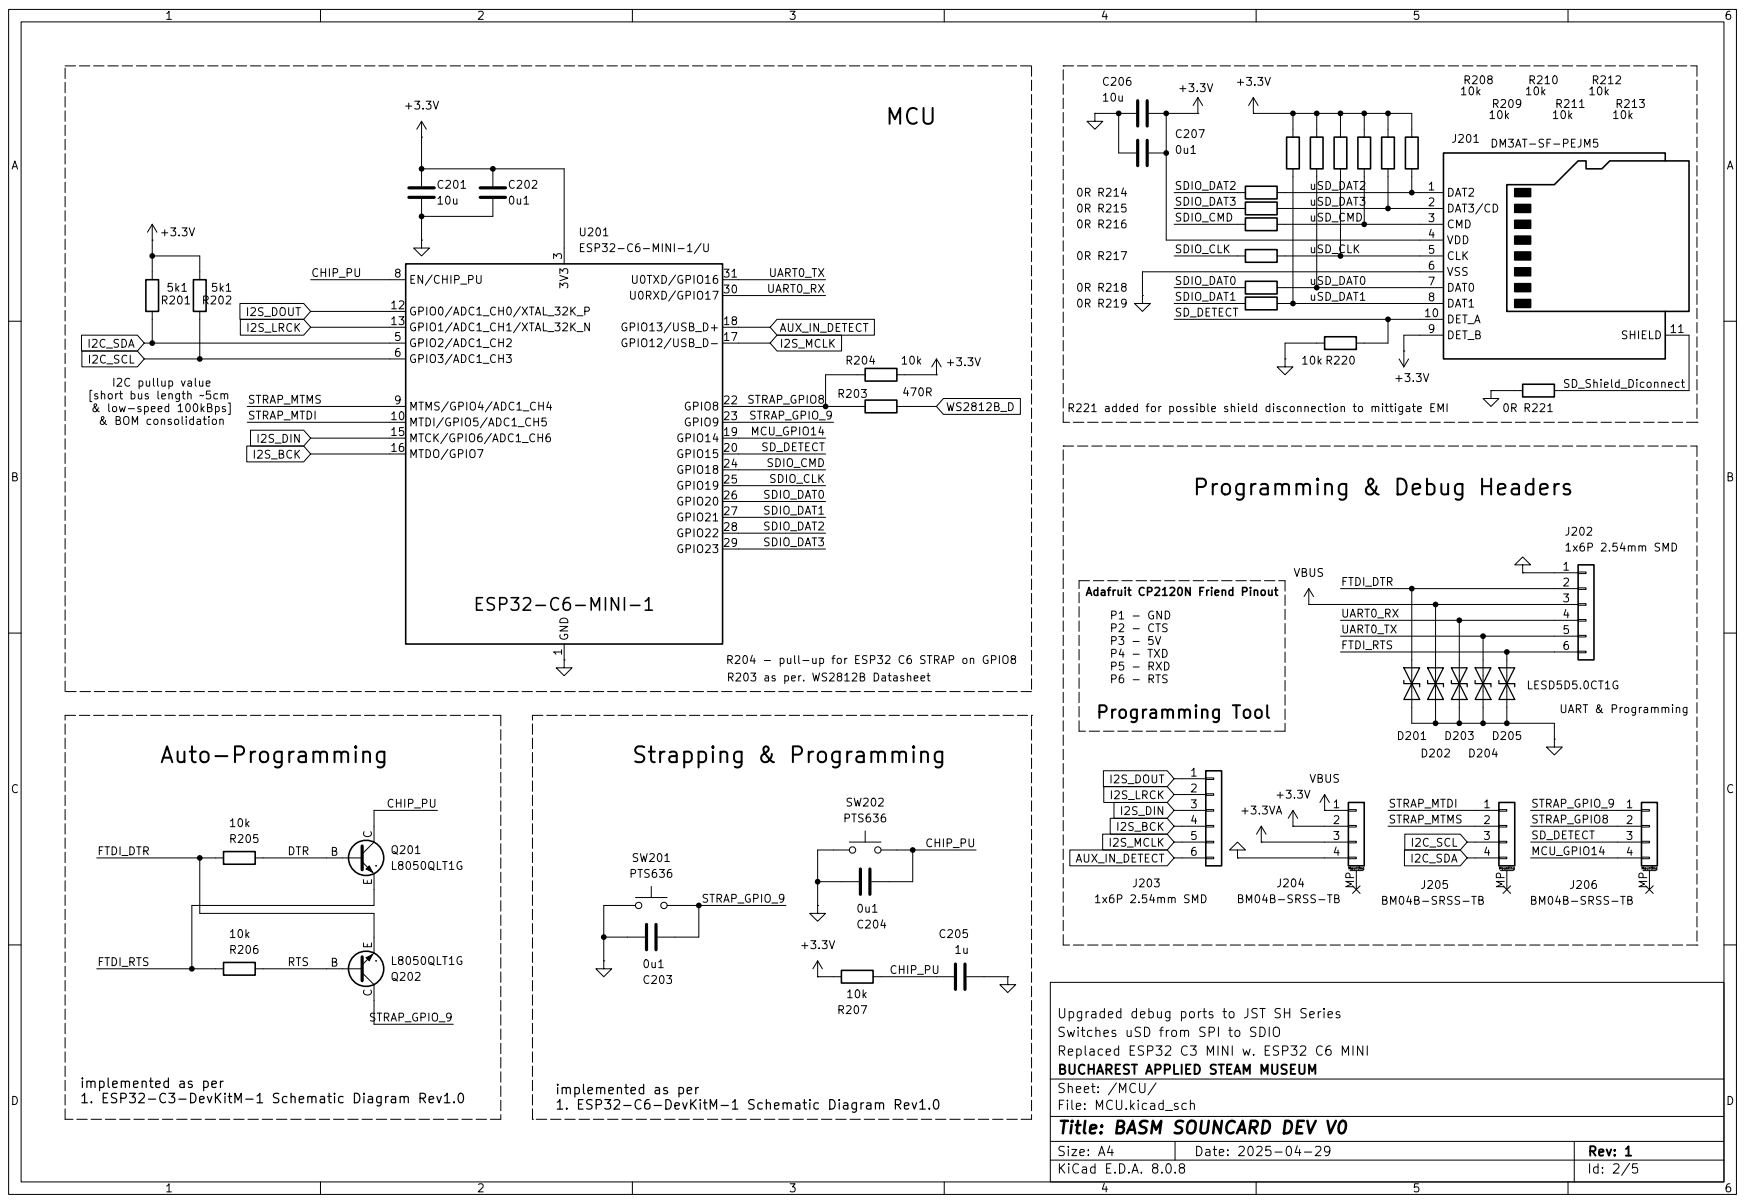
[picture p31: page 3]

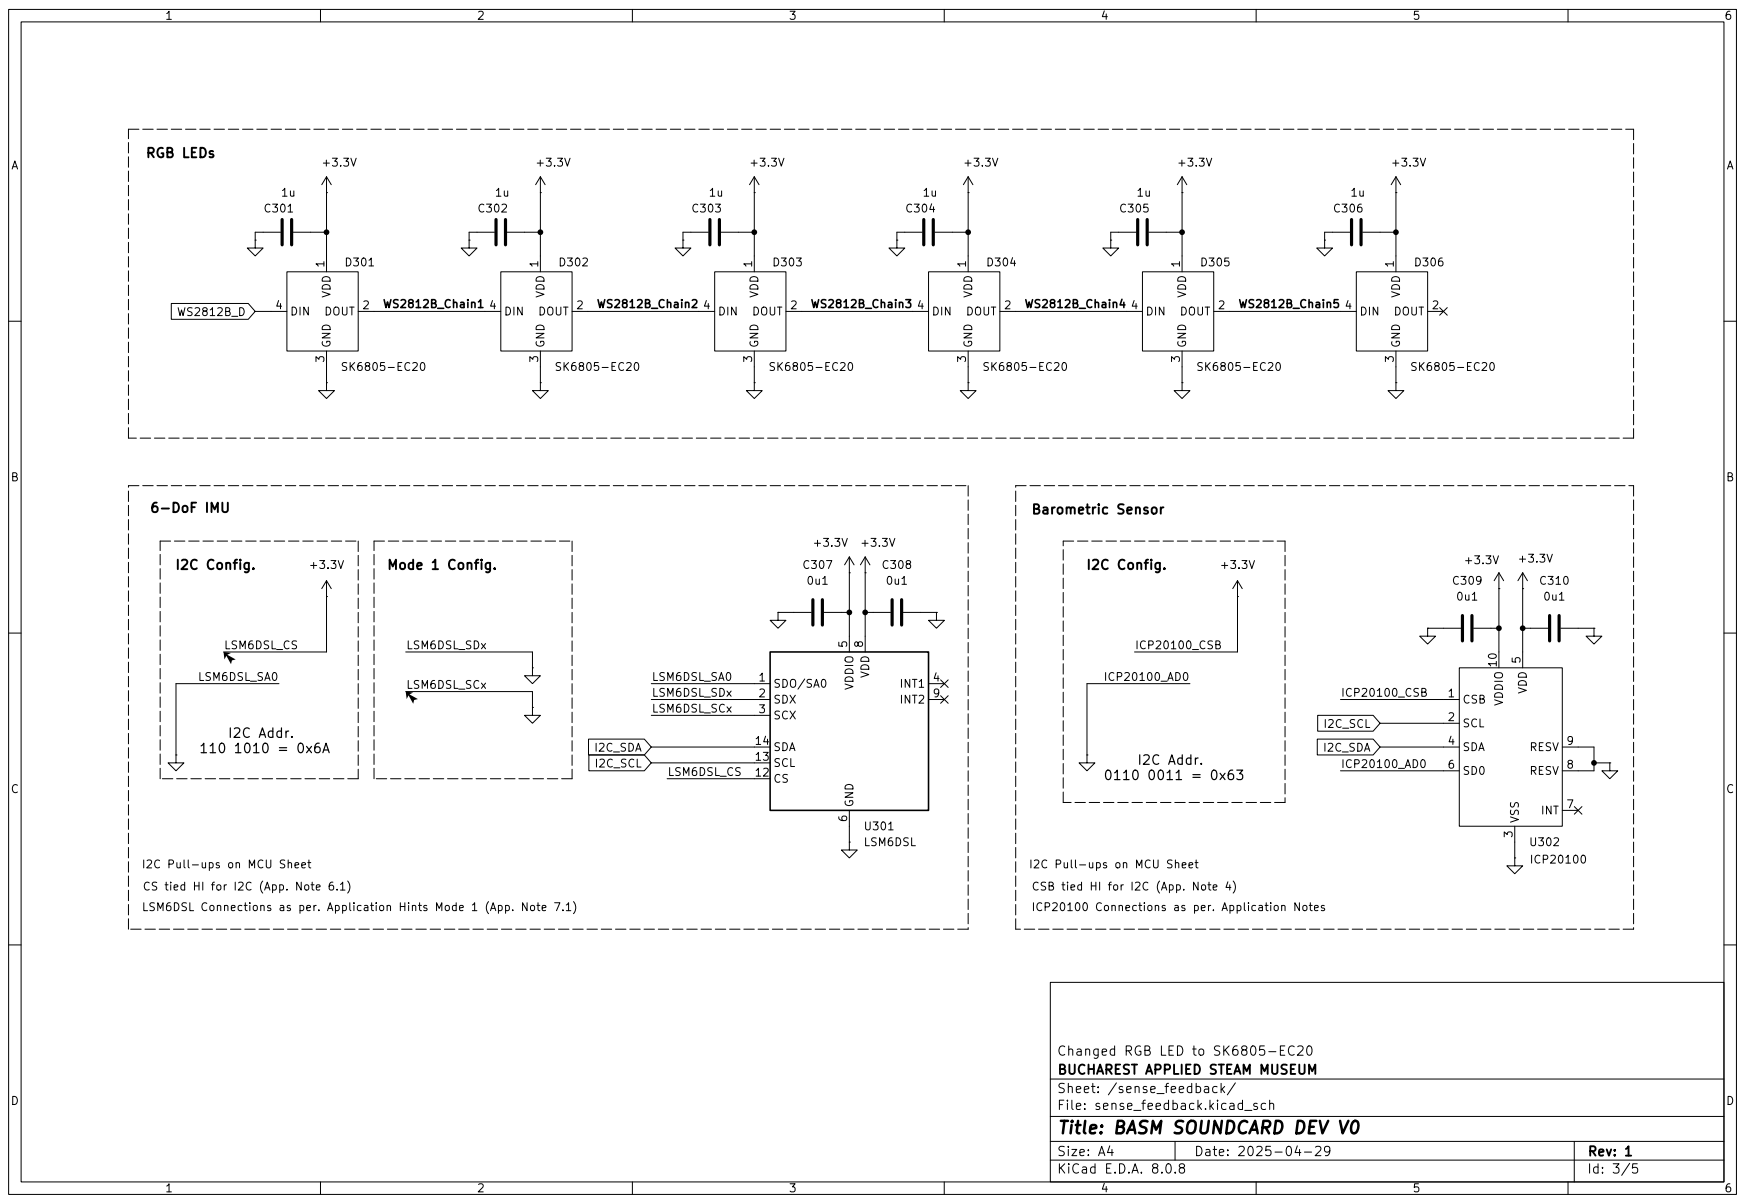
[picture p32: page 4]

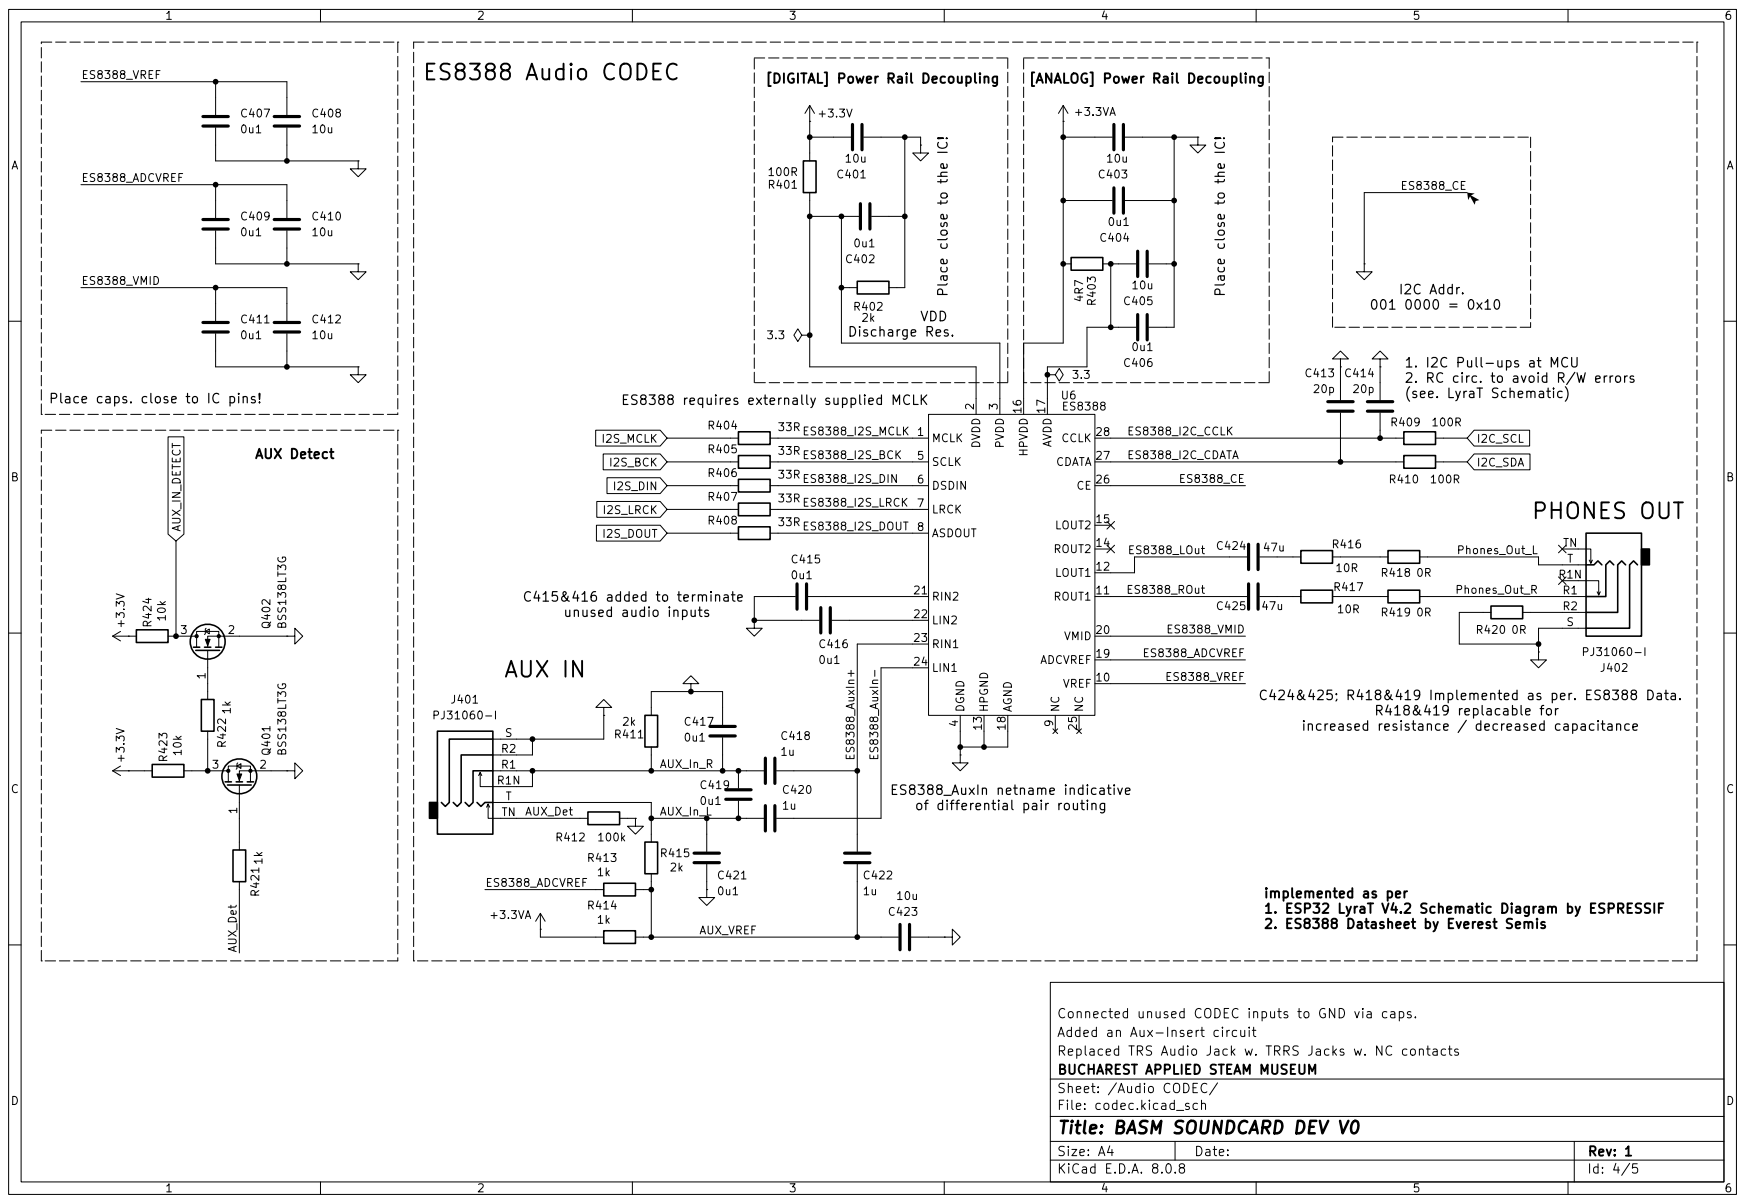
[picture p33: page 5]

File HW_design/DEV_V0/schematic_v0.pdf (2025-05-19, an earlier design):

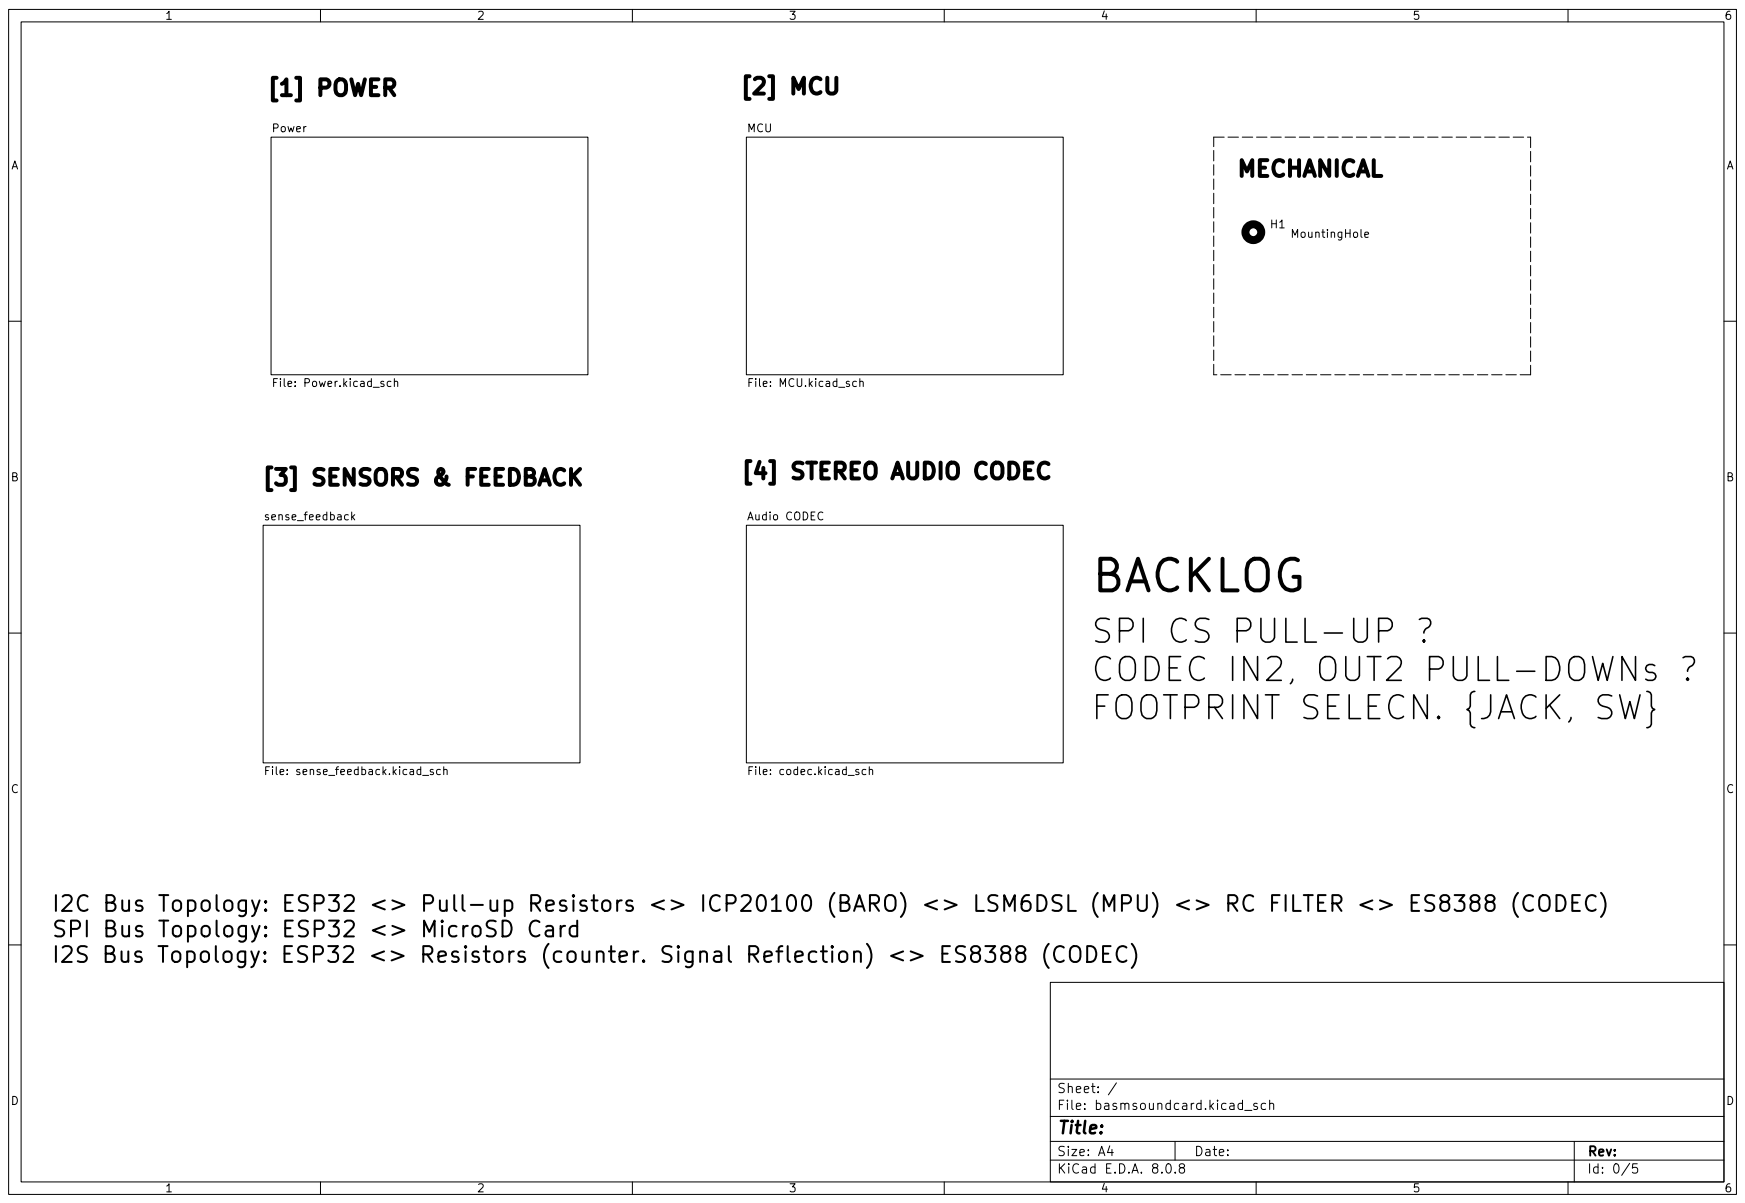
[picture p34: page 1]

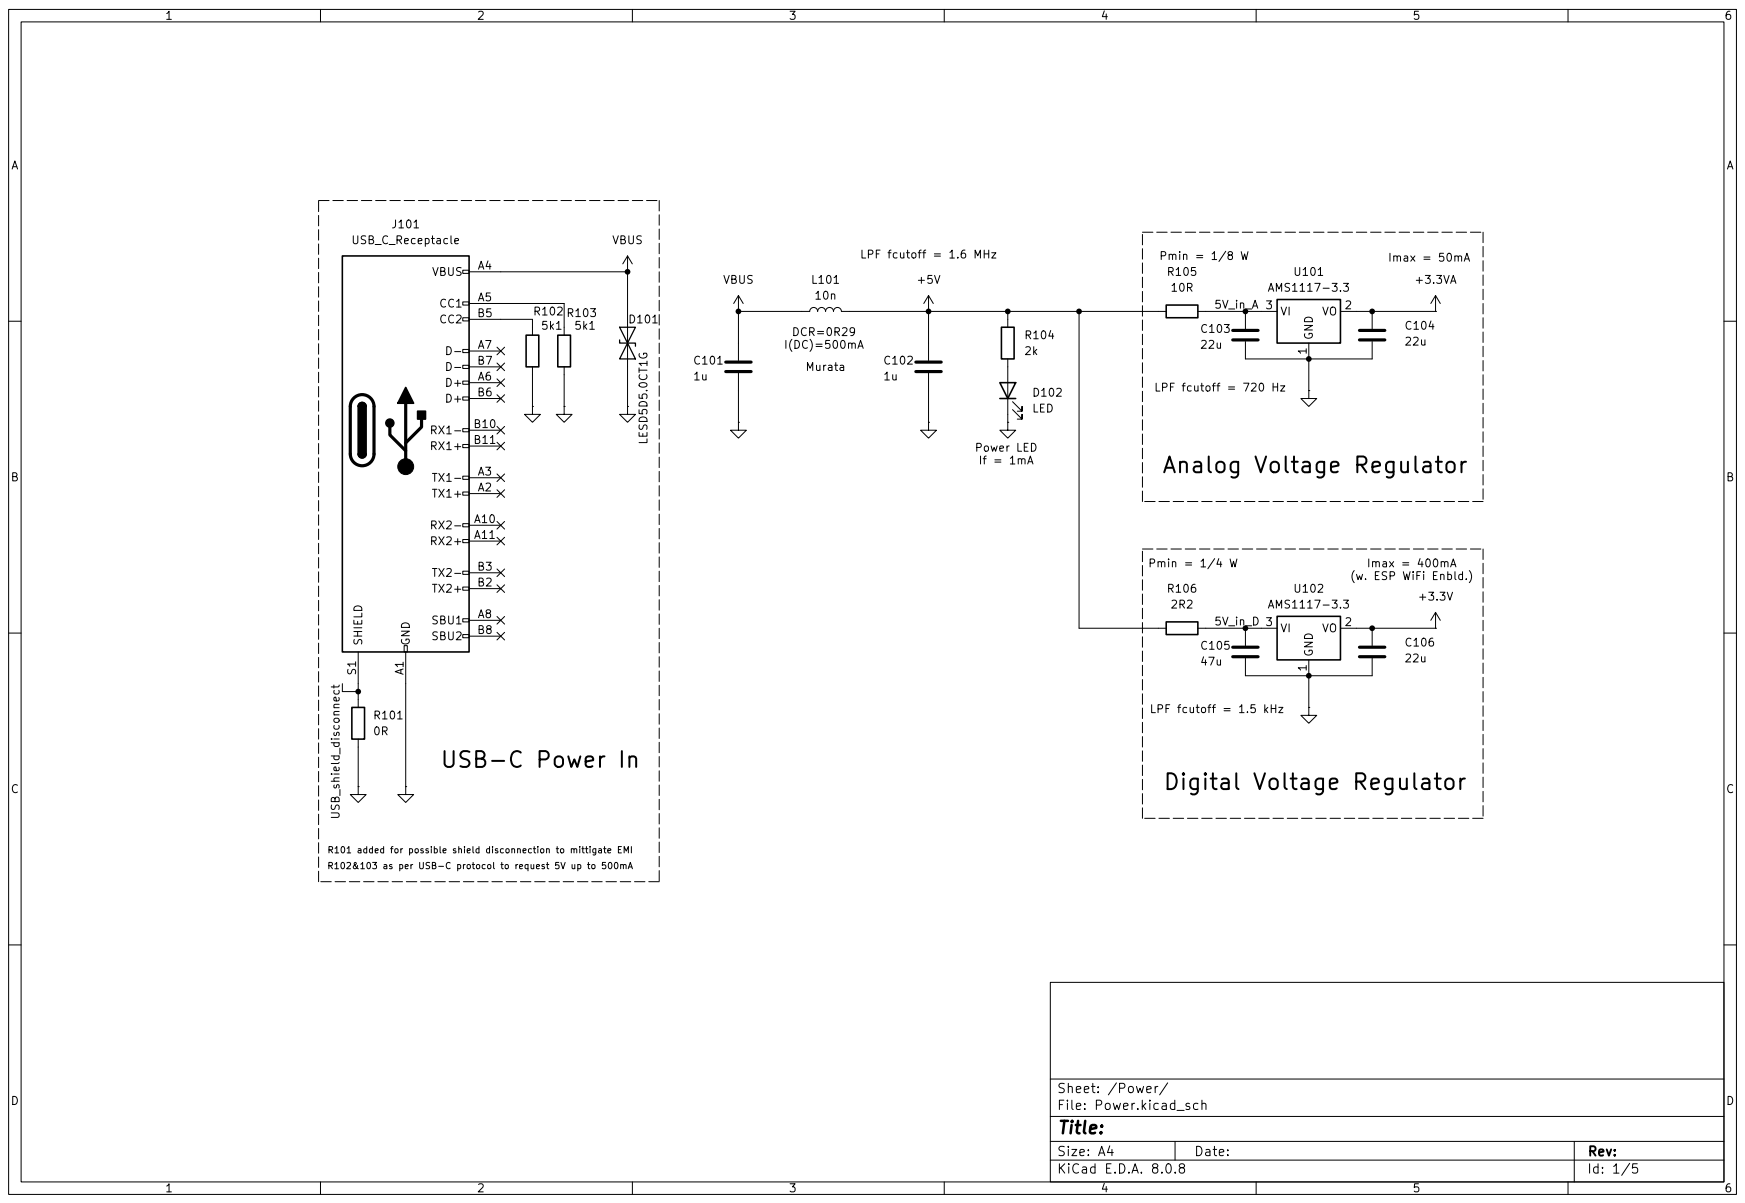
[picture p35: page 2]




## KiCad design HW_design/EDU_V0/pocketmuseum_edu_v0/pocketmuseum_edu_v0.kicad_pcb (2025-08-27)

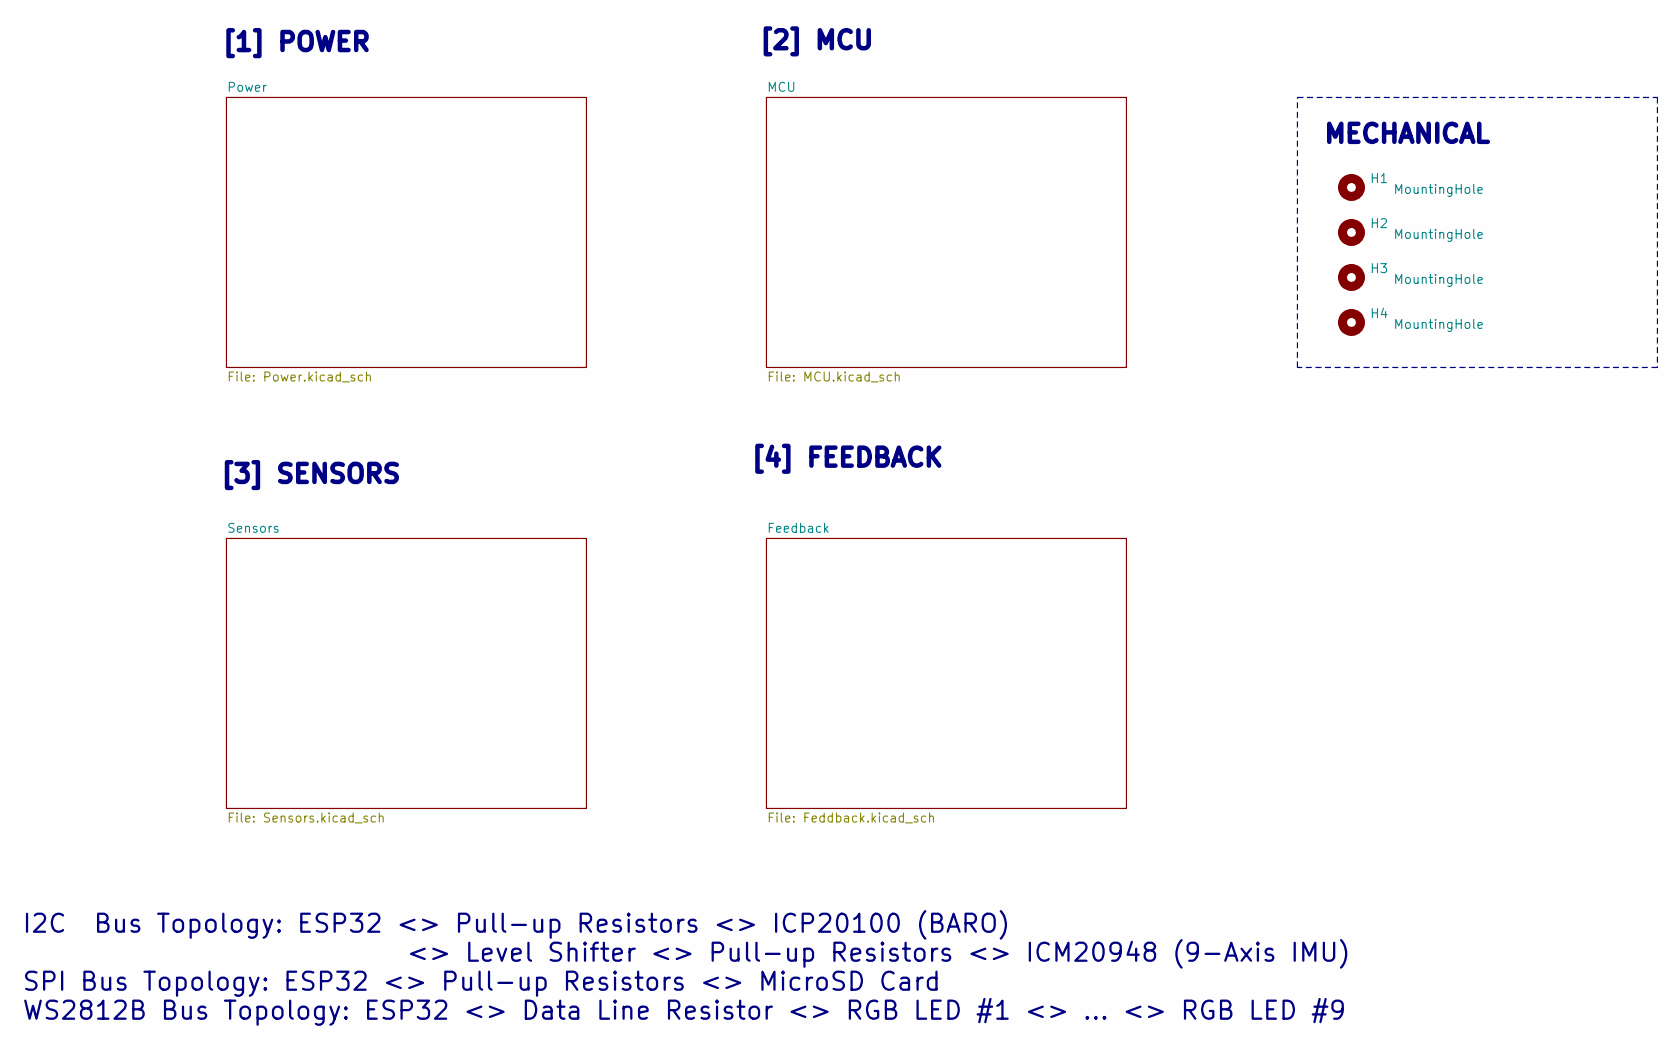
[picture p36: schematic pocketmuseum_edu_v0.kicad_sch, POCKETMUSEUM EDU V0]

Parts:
H1, H2, H3, H4: MountingHole; MountingHole_3.2mm_M3

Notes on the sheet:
[1] POWER
I2C Bus Topology: ESP32 <> Pull-up Resistors <> ICP20100 (BARO) <> Level Shifter <> Pull-up Resistors <> ICM20948 (9-Axis IMU) SPI Bus Topology: ESP32 <> Pull-up Resistors <> MicroSD Card WS2812B Bus Topology: ESP32 <> Data Line Resistor <> RGB LED #1 <> ... <> RGB LED #9
[2] MCU
[3] SENSORS
MECHANICAL
[4] FEEDBACK

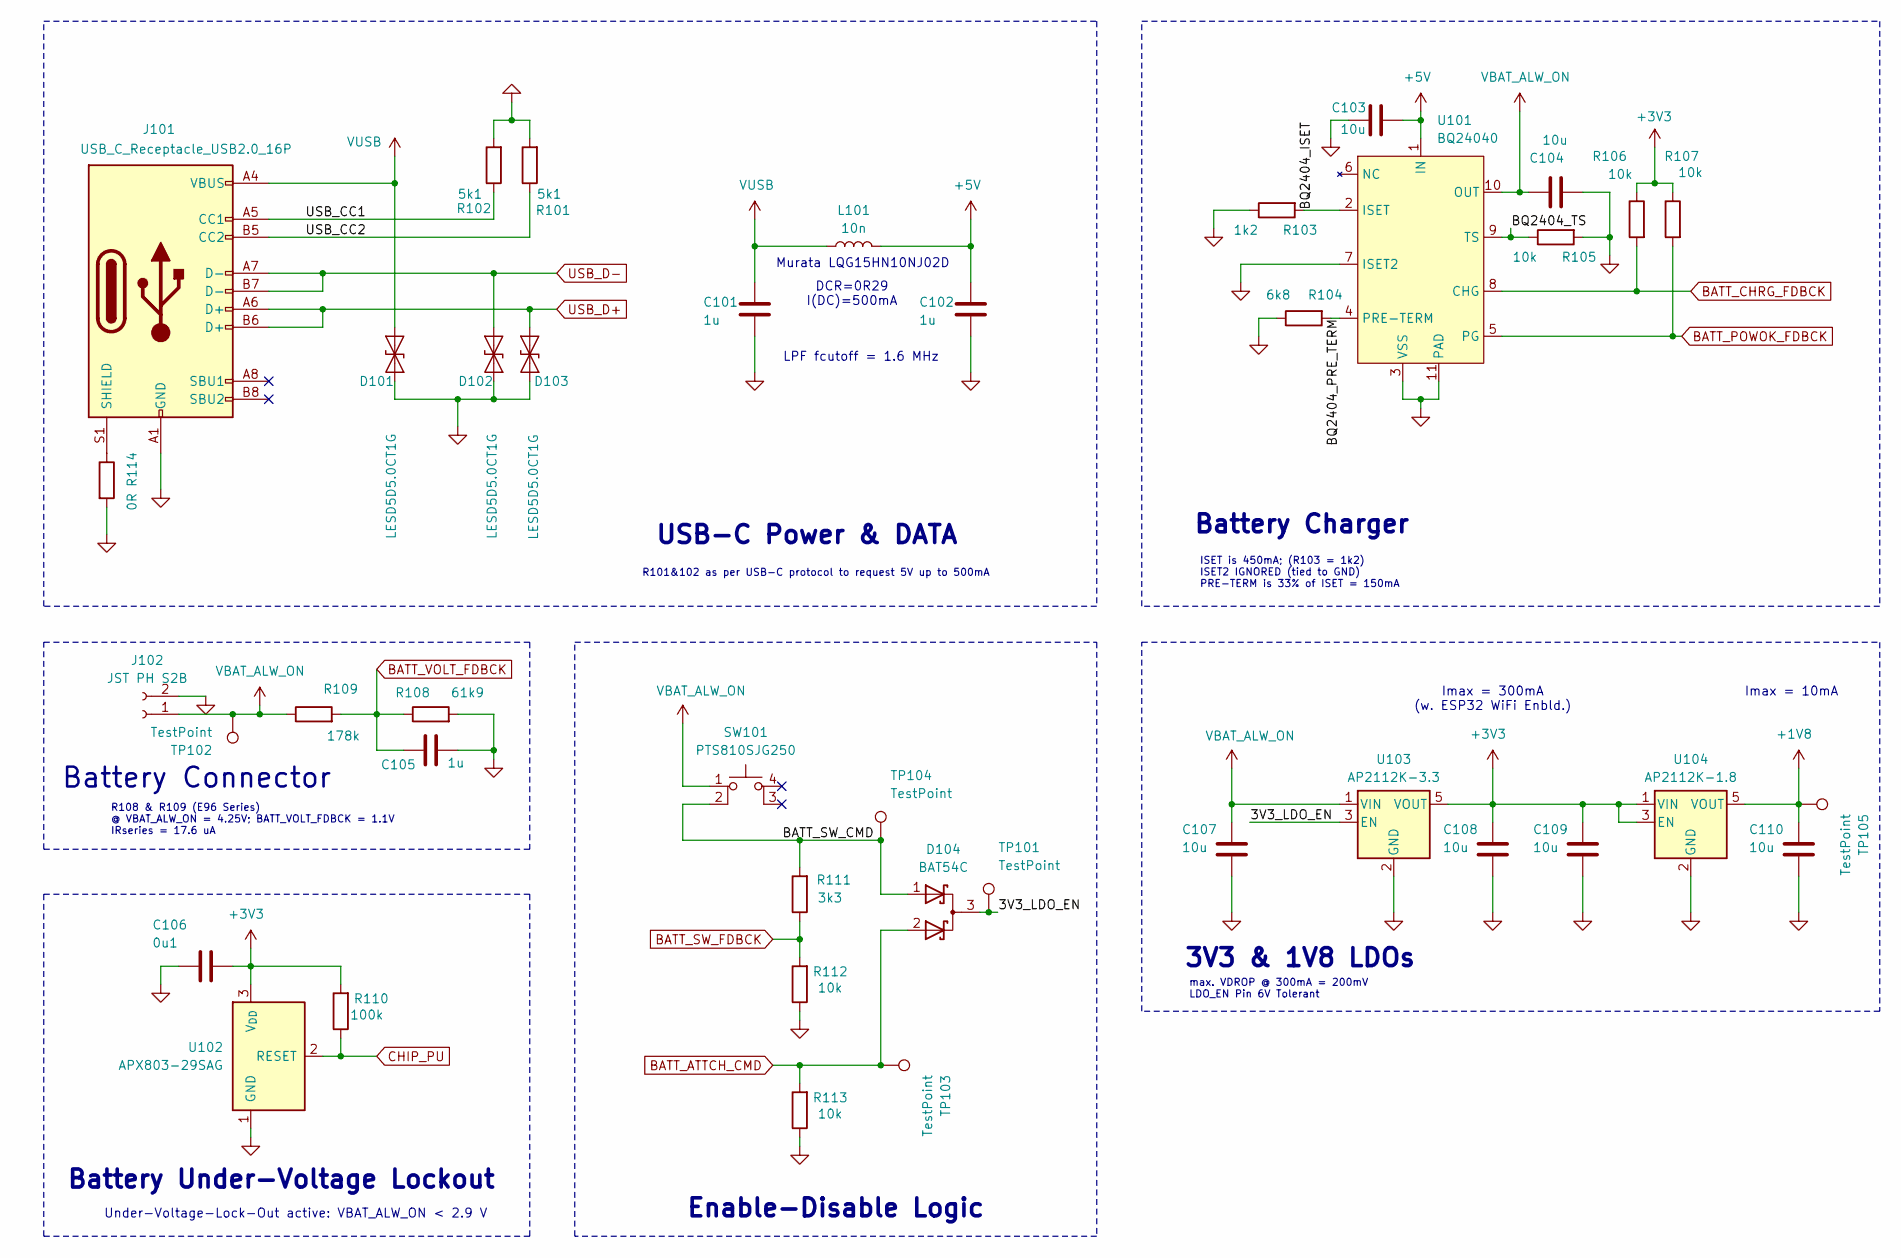
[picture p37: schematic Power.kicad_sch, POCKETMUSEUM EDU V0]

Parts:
C101, C102, C105: 1u; C_0402_1005Metric; Manufacturer P/N CL05A105KP5NNNC
C103, C104: 10u; C_0603_1608Metric; Manufacturer P/N CL05A105KP5NNNC
C106: 0u1; C_0402_1005Metric; Manufacturer P/N CL05A105KP5NNNC
C107, C108, C109, C110: 10u; C_0603_1608Metric; Manufacturer P/N CL10A226MQ8NRNC
D101, D102, D103: LESD5D5.0CT1G; D_SOD-523; Manufacturer P/N LESD5D5.0CT1G
D104: BAT54C; SOT-23
J101: USB_C_Receptacle_USB2.0_16P; USB_C_Receptacle_HRO_TYPE-C-31-M-12; Manufacturer P/N TYPE-C-31-M-12
J102: JST PH S2B; JST_PH_S2B-PH-SM4-TB_1x02-1MP_P2.00mm_Horizontal
L101: 10n; L_0402_1005Metric; Manufacturer P/N LQG15HS10NJ02D
R101, R102: 5k1; R_0402_1005Metric; Manufacturer P/N 0402WGF5101TCE
R103: 1k2; R_0402_1005Metric; Manufacturer P/N 0402WGF5101TCE
R104: 6k8; R_0402_1005Metric; Manufacturer P/N 0402WGF5101TCE
R105, R106, R107, R112, R113: 10k; R_0402_1005Metric; Manufacturer P/N 0402WGF5101TCE
R108: 61k9; R_0402_1005Metric; Manufacturer P/N 0402WGF5101TCE
R109: 178k; R_0402_1005Metric; Manufacturer P/N 0402WGF5101TCE
R110: 100k; R_0402_1005Metric; Manufacturer P/N 0402WGF5101TCE
R111: 3k3; R_0402_1005Metric; Manufacturer P/N 0402WGF5101TCE
R114: 0R; R_0603_1608Metric; Manufacturer P/N 0603WAJ0000T5E
SW101: PTS810SJG250; SW_SPST_PTS810
TP101, TP102, TP103, TP104, TP105: TestPoint; TestPoint_Pad_D2.0mm
U101: BQ24040; QFN_10_BQ24040
U102: APX803-29SAG; SOT-23
U103: AP2112K-3.3; SOT-23-5
U104: AP2112K-1.8; SOT-23-5

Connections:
+1V8: C110.1, TP105.1, U104.5 (VOUT); also elsewhere on the board
+3V3: C106.1, C108.1, C109.1, R106.1, R107.1, R110.2, U102.3 (V_{DD}), U103.5 (VOUT), U104.1 (VIN), U104.3 (EN); also elsewhere on the board
+5V: C102.1, C103.1, L101.2, U101.1 (IN)
/Power/3V3_LDO_EN: D104.3 (K), TP101.1, U103.3 (EN)
/Power/BATT_SW_CMD: D104.1 (A), R111.2, SW101.2, TP104.1
/Power/BQ2404_ISET: R103.2, U101.2 (ISET)
/Power/BQ2404_PRE_TERM: R104.2, U101.4 (PRE-TERM)
/Power/BQ2404_TS: R105.1, U101.9 (TS)
/Power/USB_CC1: J101.A5 (CC1), R102.1
/Power/USB_CC2: J101.B5 (CC2), R101.1
BATT_ATTCH_CMD: D104.2 (A), R113.2, TP103.1; also elsewhere on the board
BATT_CHRG_FDBCK: R106.2, U101.8 (CHG); also elsewhere on the board
BATT_POWOK_FDBCK: R107.2, U101.5 (PG); also elsewhere on the board
BATT_SW_FDBCK: R111.1, R112.2; also elsewhere on the board
BATT_VOLT_FDBCK: C105.1, R108.1, R109.2; also elsewhere on the board
CHIP_PU: R110.1, U102.2 (RESET); also elsewhere on the board
GND: C101.2, C102.2, C103.2, C104.2, C105.2, C106.2, C107.2, C108.2, C109.2, C110.2, D101.2 (A2), D102.2 (A2), D103.1 (A1), J101.A1 (GND), J101.A12 (GND), J101.B1 (GND), J101.B12 (GND), J102.2, R101.2, R102.2, R103.1, R104.1, R105.2, R108.2, R112.1, R113.1, R114.2, U101.3 (VSS), U101.7 (ISET2), U101.11 (PAD), U102.1 (GND), U103.2 (GND), U104.2 (GND); also elsewhere on the board
unnamed: J101.S1 (SHIELD), R114.1
USB_D+: D103.2 (A2), J101.A6 (D+), J101.B6 (D+); also elsewhere on the board
USB_D-: D102.1 (A1), J101.A7 (D-), J101.B7 (D-); also elsewhere on the board
VBAT_ALW_ON: C104.1, C107.1, J102.1, R109.1, SW101.1, TP102.1, U101.10 (OUT), U103.1 (VIN)
VUSB: C101.1, D101.1 (A1), J101.A4 (VBUS), J101.A9 (VBUS), J101.B4 (VBUS), J101.B9 (VBUS), L101.1

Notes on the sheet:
Murata LQG15HN10NJ02D
Under-Voltage-Lock-Out active: VBAT_ALW_ON < 2.9 V
Battery Connector
Imax = 300mA (w. ESP32 WiFi Enbld.)
ISET is 450mA; (R103 = 1k2) ISET2 IGNORED (tied to GND) PRE-TERM is 33% of ISET = 150mA
Battery Charger
DCR=0R29 I(DC)=500mA
USB-C Power & DATA
Battery Under-Voltage Lockout
R108 & R109 (E96 Series) @ VBAT_ALW_ON = 4.25V; BATT_VOLT_FDBCK = 1.1V IRseries = 17.6 uA
Enable-Disable Logic
max. VDROP @ 300mA = 200mV LDO_EN Pin 6V Tolerant
Imax = 10mA
LPF fcutoff = 1.6 MHz
3V3 & 1V8 LDOs
R101&102 as per USB-C protocol to request 5V up to 500mA

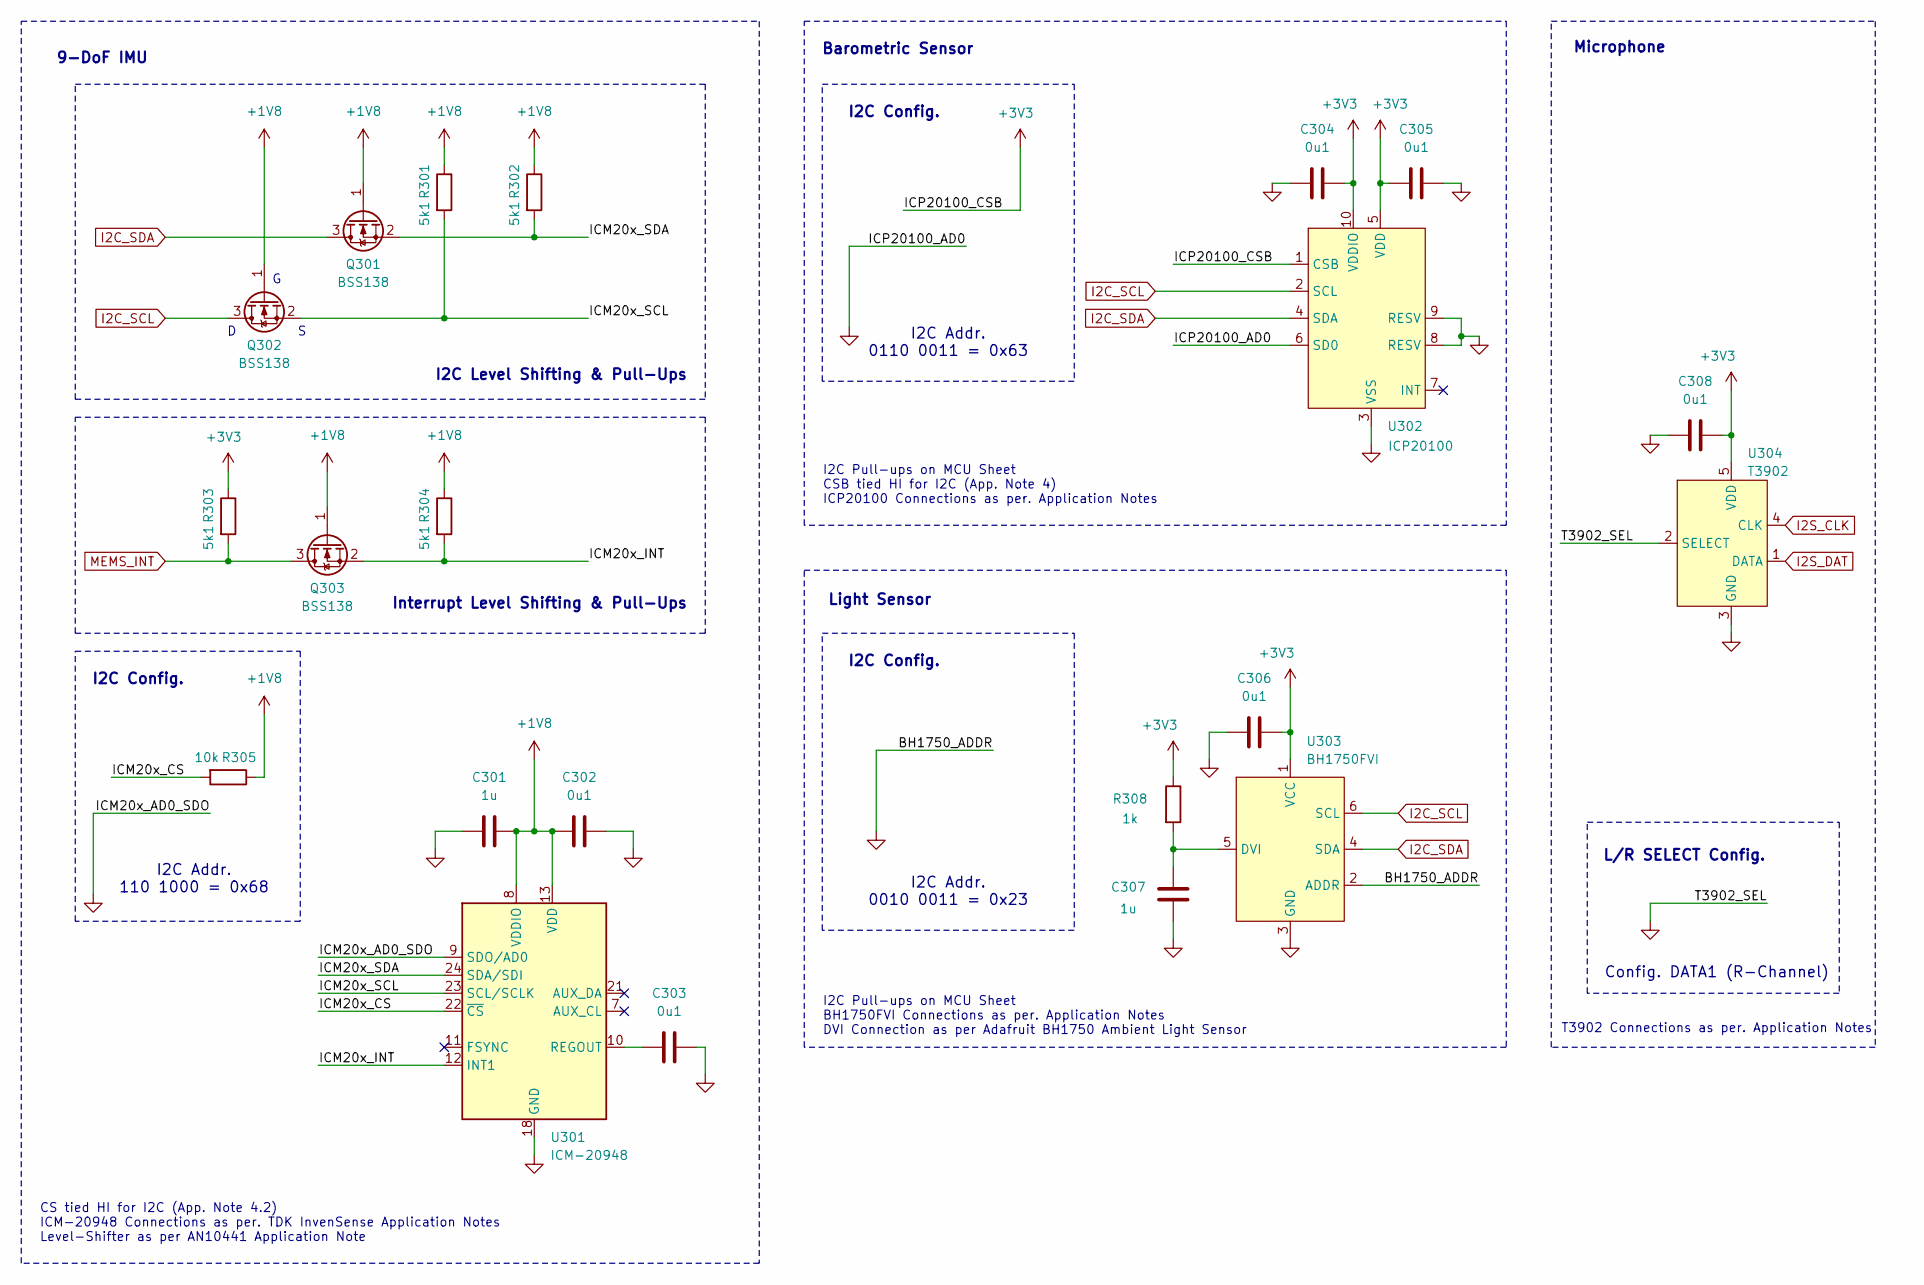
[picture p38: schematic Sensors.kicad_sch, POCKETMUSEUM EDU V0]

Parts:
C301, C307: 1u; C_0402_1005Metric; Manufacturer P/N CL05B104KO5NNNC
C302, C303, C304, C305, C306, C308: 0u1; C_0402_1005Metric; Manufacturer P/N CL05B104KO5NNNC
Q301, Q302, Q303: BSS138; SOT-23
R301, R302, R303, R304: 5k1; R_0402_1005Metric; Manufacturer P/N 0603WAJ0000T5E
R305: 10k; R_0402_1005Metric; Manufacturer P/N 0603WAJ0000T5E
R308: 1k; R_0402_1005Metric; Manufacturer P/N 0603WAJ0000T5E
U301: ICM-20948; InvenSense_QFN-24_3x3mm_P0.4mm
U302: ICP20100; ST_HLGA-10_2x2mm_P0.5mm_LayoutBorder3x2y; Manufacturer P/N ICP-20100
U303: BH1750FVI; XDCR_BH1750FVI-TR
U304: T3902; MMIC

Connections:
+1V8: C301.1, C302.2, Q301.1 (G), Q302.1 (G), Q303.1 (G), R301.1, R302.1, R304.1, R305.1, U301.8 (VDDIO), U301.13 (VDD); also elsewhere on the board
+3V3: C304.1, C305.2, C306.1, C308.1, R303.1, R308.1, U302.1 (CSB), U302.5 (VDD), U302.10 (VDDIO), U303.1 (VCC), U304.5 (VDD); also elsewhere on the board
/Sensors/ICM20x_CS: R305.2, U301.22 (~CS)
/Sensors/ICM20x_INT: Q303.2 (S), R304.2, U301.12 (INT1)
/Sensors/ICM20x_SCL: Q302.2 (S), R301.2, U301.23 (SCL/SCLK)
/Sensors/ICM20x_SDA: Q301.2 (S), R302.2, U301.24 (SDA/SDI)
GND: C301.2, C302.1, C303.1, C304.2, C305.1, C306.2, C307.2, C308.2, U301.9 (SDO/AD0), U301.18 (GND), U301.20 (GND), U302.3 (VSS), U302.6 (SD0), U302.8 (RESV), U302.9 (RESV), U303.2 (ADDR), U303.3 (GND), U304.2 (SELECT), U304.3 (GND); also elsewhere on the board
I2C_SCL: Q302.3 (D), U302.2 (SCL), U303.6 (SCL); also elsewhere on the board
I2C_SDA: Q301.3 (D), U302.4 (SDA), U303.4 (SDA); also elsewhere on the board
I2S_CLK: U304.4 (CLK); also elsewhere on the board
I2S_DAT: U304.1 (DATA); also elsewhere on the board
MEMS_INT: Q303.3 (D), R303.2; also elsewhere on the board
unnamed: C303.2, U301.10 (REGOUT)
unnamed: C307.1, R308.2, U303.5 (DVI)

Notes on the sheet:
I2C Pull-ups on MCU Sheet BH1750FVI Connections as per. Application Notes DVI Connection as per Adafruit BH1750 Ambient Light Sensor
I2C Pull-ups on MCU Sheet CSB tied HI for I2C (App. Note 4) ICP20100 Connections as per. Application Notes
T3902 Connections as per. Application Notes
I2C Config.
Microphone
I2C Addr. 0110 0011 = 0x63
I2C Addr. 110 1000 = 0x68
I2C Addr. 0010 0011 = 0x23
9-DoF IMU
Config. DATA1 (R-Channel)
Light Sensor
CS tied HI for I2C (App. Note 4.2) ICM-20948 Connections as per. TDK InvenSense Application Notes Level-Shifter as per AN10441 Application Note
I2C Level Shifting & Pull-Ups
Barometric Sensor
L/R SELECT Config.
Interrupt Level Shifting & Pull-Ups

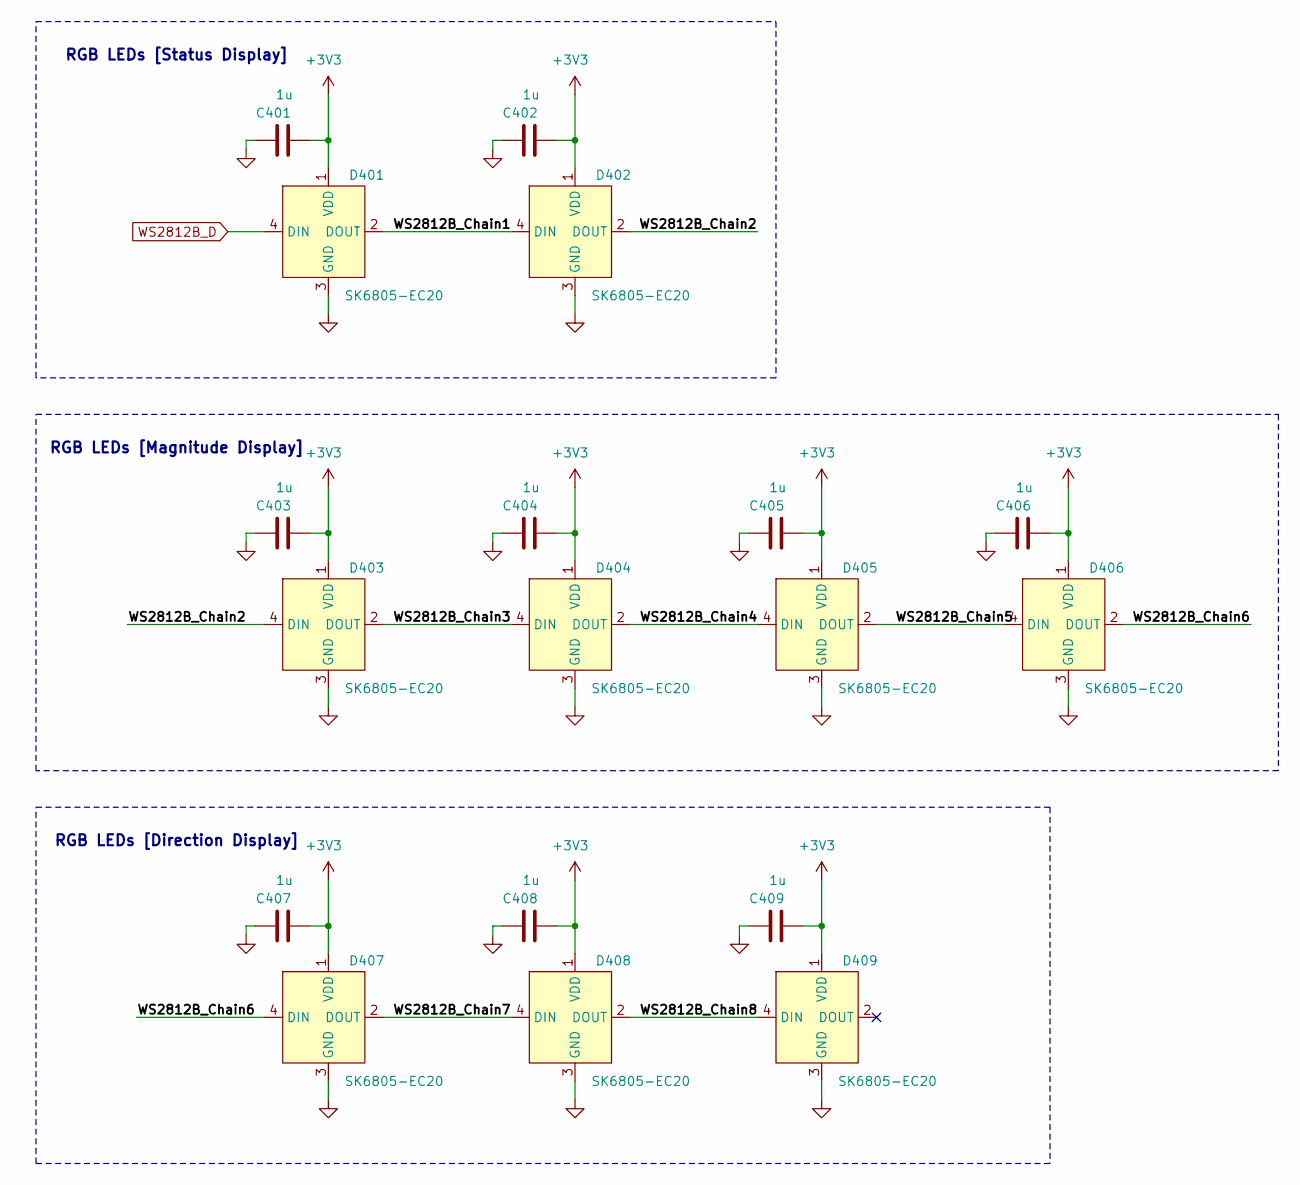
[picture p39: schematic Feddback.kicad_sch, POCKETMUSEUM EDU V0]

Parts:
C401, C402, C403, C404, C405, C406, C407, C408, C409: 1u; C_0402_1005Metric; Manufacturer P/N CL05A105KP5NNNC
D401, D402, D403, D404, D405, D406, D407, D408, D409: SK6805-EC20; SK68xx-EC20; Manufacturer P/N SK6805-EC20

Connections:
+3V3: C401.2, C402.2, C403.2, C404.2, C405.2, C406.2, C407.2, C408.2, C409.2, D401.1 (VDD), D402.1 (VDD), D403.1 (VDD), D404.1 (VDD), D405.1 (VDD), D406.1 (VDD), D407.1 (VDD), D408.1 (VDD), D409.1 (VDD); also elsewhere on the board
/Feedback/WS2812B_Chain1: D401.2 (DOUT), D402.4 (DIN)
/Feedback/WS2812B_Chain2: D402.2 (DOUT), D403.4 (DIN)
/Feedback/WS2812B_Chain3: D403.2 (DOUT), D404.4 (DIN)
/Feedback/WS2812B_Chain4: D404.2 (DOUT), D405.4 (DIN)
/Feedback/WS2812B_Chain5: D405.2 (DOUT), D406.4 (DIN)
/Feedback/WS2812B_Chain6: D406.2 (DOUT), D407.4 (DIN)
/Feedback/WS2812B_Chain7: D407.2 (DOUT), D408.4 (DIN)
/Feedback/WS2812B_Chain8: D408.2 (DOUT), D409.4 (DIN)
GND: C401.1, C402.1, C403.1, C404.1, C405.1, C406.1, C407.1, C408.1, C409.1, D401.3 (GND), D402.3 (GND), D403.3 (GND), D404.3 (GND), D405.3 (GND), D406.3 (GND), D407.3 (GND), D408.3 (GND), D409.3 (GND); also elsewhere on the board
WS2812B_D: D401.4 (DIN); also elsewhere on the board

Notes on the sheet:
RGB LEDs [Magnitude Display]
RGB LEDs [Direction Display]
RGB LEDs [Status Display]

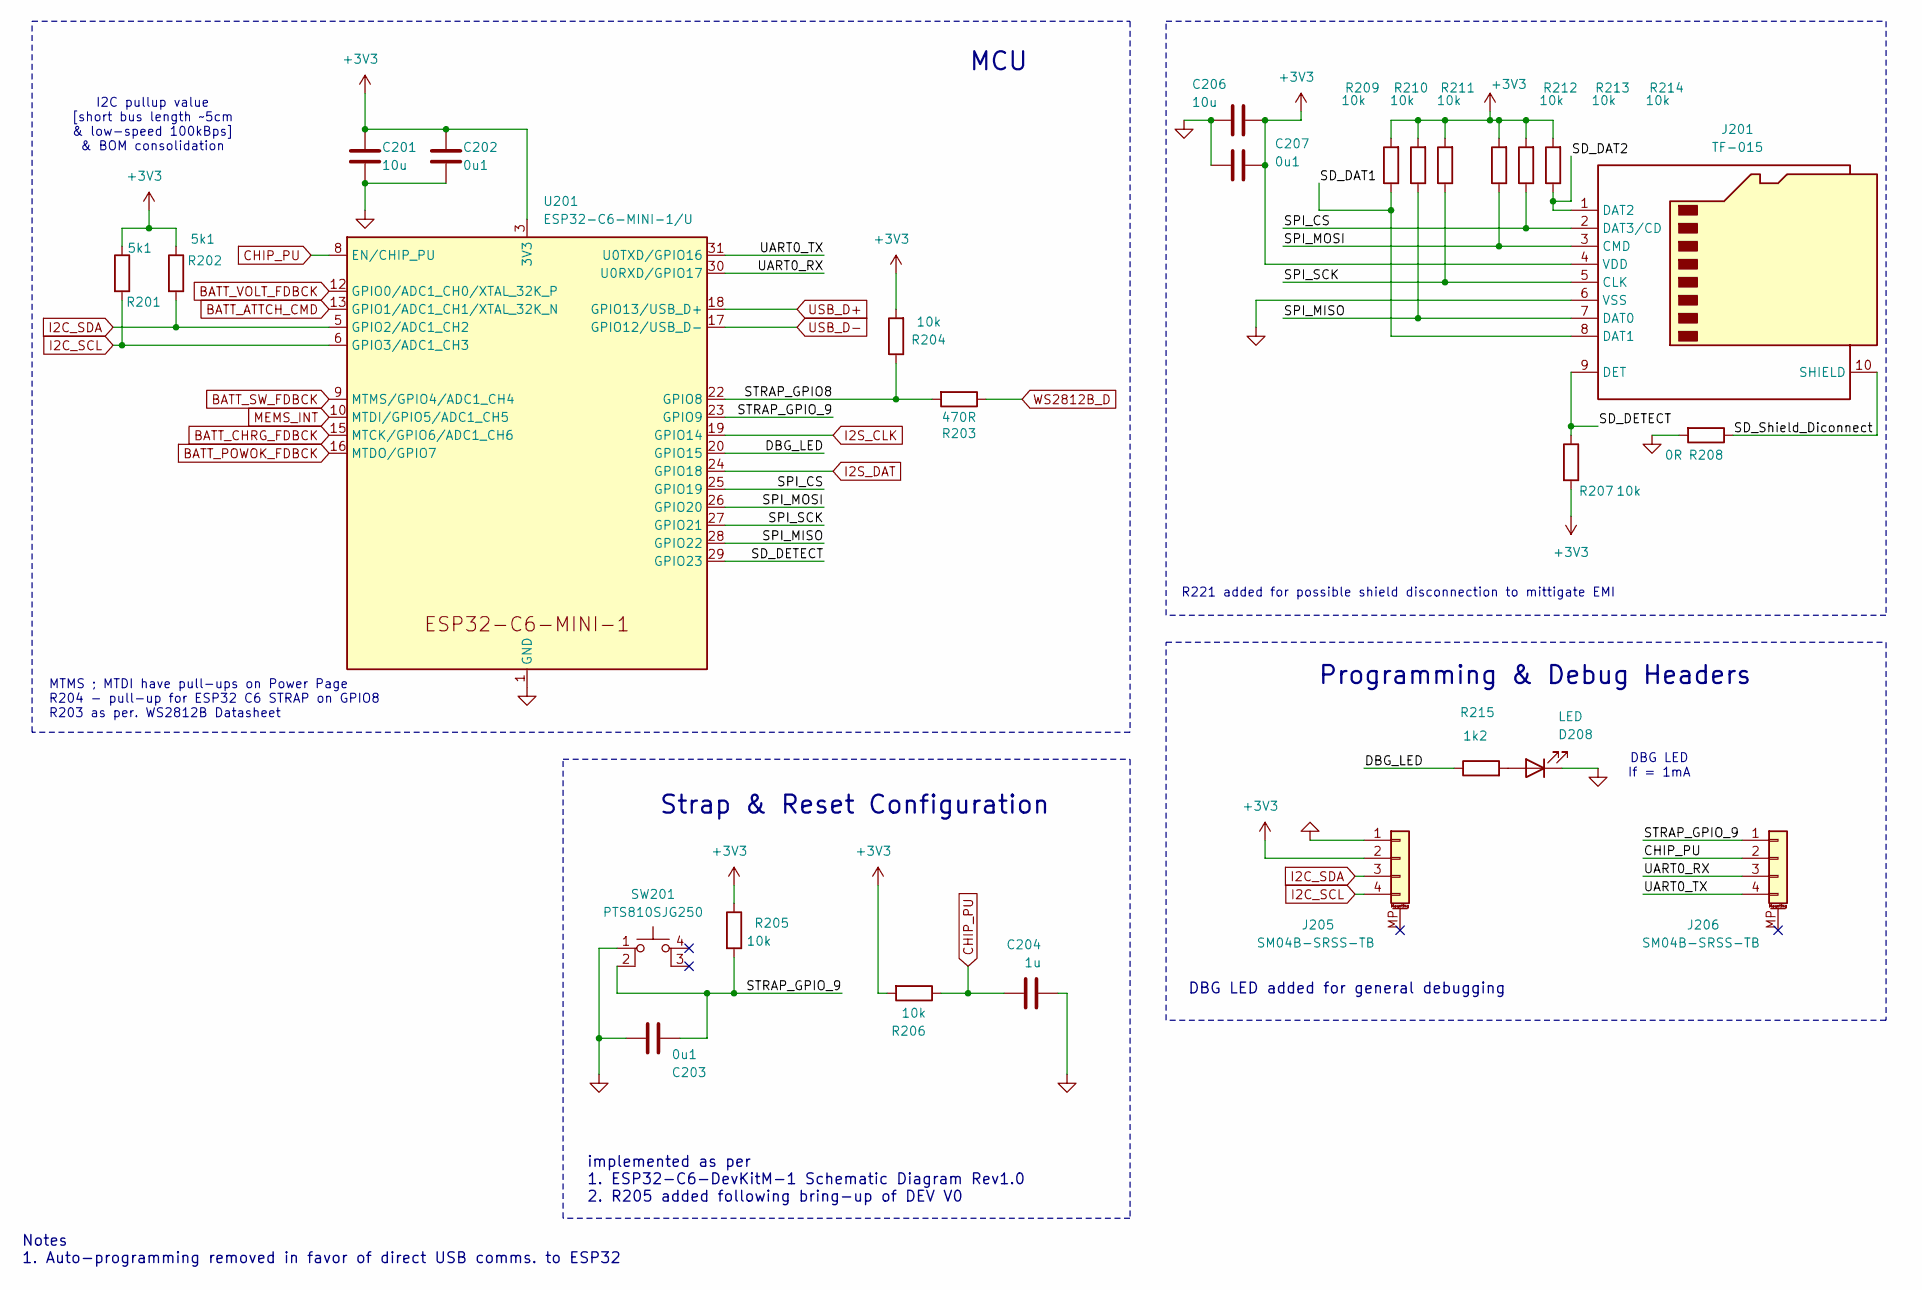
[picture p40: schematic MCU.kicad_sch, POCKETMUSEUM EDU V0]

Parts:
C201, C206: 10u; C_0603_1608Metric; Manufacturer P/N CL10A106MQ8NNNC
C202, C203, C207: 0u1; C_0402_1005Metric; Manufacturer P/N CL05B104KO5NNNC
C204: 1u; C_0402_1005Metric; Manufacturer P/N CL05A105KP5NNNC
D208: LED; LED_0402_1005Metric; Manufacturer P/N YLED0402R
J201: TF-015; TF-015_SOFNG
J205, J206: SM04B-SRSS-TB; JST_SH_SM04B-SRSS-TB_1x04-1MP_P1.00mm_Horizontal; Manufacturer P/N BM04B-SRSS-TB(LF)(SN)
R201, R202: 5k1; R_0402_1005Metric; Manufacturer P/N 0402WGF5101TCE
R203: 470R; R_0402_1005Metric; Manufacturer P/N 0402WGF4700TCE
R204, R205, R206, R207, R209, R210, R211, R212, R213, R214: 10k; R_0402_1005Metric; Manufacturer P/N 0402WGF1002TCE
R208: 0R; R_0603_1608Metric; Manufacturer P/N 0603WAJ0000T5E
R215: 1k2; R_0402_1005Metric; Manufacturer P/N 0402WGF2001TCE
SW201: PTS810SJG250; SW_SPST_PTS810
U201: ESP32-C6-MINI-1/U; ESP32-C6-MINI-1; Manufacturer P/N ESP32-C6-MINI-1-N4

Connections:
+3V3: C201.1, C202.1, C206.1, C207.1, J201.4 (VDD), J205.2, R201.1, R202.1, R204.2, R205.1, R206.2, R207.2, R209.2, R210.2, R211.2, R212.2, R213.2, R214.2, U201.3 (3V3); also elsewhere on the board
/MCU/DBG_LED: R215.1, U201.20 (GPIO15)
/MCU/SD_DAT1: J201.8 (DAT1), R209.1
/MCU/SD_DAT2: J201.1 (DAT2), R214.1
/MCU/SD_DETECT: J201.9 (DET), R207.1, U201.29 (GPIO23)
/MCU/SD_Shield_Diconnect: J201.10 (SHIELD), R208.1
/MCU/SPI_CS: J201.2 (DAT3/CD), R213.1, U201.25 (GPIO19)
/MCU/SPI_MISO: J201.7 (DAT0), R210.1, U201.28 (GPIO22)
/MCU/SPI_MOSI: J201.3 (CMD), R212.1, U201.26 (GPIO20)
/MCU/SPI_SCK: J201.5 (CLK), R211.1, U201.27 (GPIO21)
/MCU/STRAP_GPIO8: R203.2, R204.1, U201.22 (GPIO8)
/MCU/STRAP_GPIO_9: C203.1, J206.1, R205.2, SW201.2, U201.23 (GPIO9)
/MCU/UART0_RX: J206.3, U201.30 (U0RXD/GPIO17)
/MCU/UART0_TX: J206.4, U201.31 (U0TXD/GPIO16)
BATT_ATTCH_CMD: U201.13 (GPIO1/ADC1_CH1/XTAL_32K_N); also elsewhere on the board
BATT_CHRG_FDBCK: U201.15 (MTCK/GPIO6/ADC1_CH6); also elsewhere on the board
BATT_POWOK_FDBCK: U201.16 (MTDO/GPIO7); also elsewhere on the board
BATT_SW_FDBCK: U201.9 (MTMS/GPIO4/ADC1_CH4); also elsewhere on the board
BATT_VOLT_FDBCK: U201.12 (GPIO0/ADC1_CH0/XTAL_32K_P); also elsewhere on the board
CHIP_PU: C204.1, J206.2, R206.1, U201.8 (EN/CHIP_PU); also elsewhere on the board
GND: C201.2, C202.2, C203.2, C204.2, C206.2, C207.2, D208.1 (K), J201.6 (VSS), J205.1, R208.2, SW201.1, U201.1 (GND), U201.2 (GND), U201.11 (GND), U201.14 (GND), U201.36 (GND), U201.37 (GND), U201.38 (GND), U201.39 (GND), U201.40 (GND), U201.41 (GND), U201.42 (GND), U201.43 (GND), U201.44 (GND), U201.45 (GND), U201.46 (GND), U201.47 (GND), U201.48 (GND), U201.49 (GND), U201.50 (GND), U201.51 (GND), U201.52 (GND), U201.53 (GND); also elsewhere on the board
I2C_SCL: J205.4, R201.2, U201.6 (GPIO3/ADC1_CH3); also elsewhere on the board
I2C_SDA: J205.3, R202.2, U201.5 (GPIO2/ADC1_CH2); also elsewhere on the board
I2S_CLK: U201.19 (GPIO14); also elsewhere on the board
I2S_DAT: U201.24 (GPIO18); also elsewhere on the board
MEMS_INT: U201.10 (MTDI/GPIO5/ADC1_CH5); also elsewhere on the board
unnamed: D208.2 (A), R215.2
USB_D+: U201.18 (GPIO13/USB_D+); also elsewhere on the board
USB_D-: U201.17 (GPIO12/USB_D-); also elsewhere on the board
WS2812B_D: R203.1; also elsewhere on the board

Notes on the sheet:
DBG LED If = 1mA
DBG LED added for general debugging
Programming & Debug Headers
R221 added for possible shield disconnection to mittigate EMI
implemented as per 1. ESP32-C6-DevKitM-1 Schematic Diagram Rev1.0 2. R205 added following bring-up of DEV V0
Strap & Reset Configuration
MTMS ; MTDI have pull-ups on Power Page R204 - pull-up for ESP32 C6 STRAP on GPIO8 R203 as per. WS2812B Datasheet
I2C pullup value [short bus length ~5cm & low-speed 100kBps] & BOM consolidation
MCU
Notes 1. Auto-programming removed in favor of direct USB comms. to ESP32

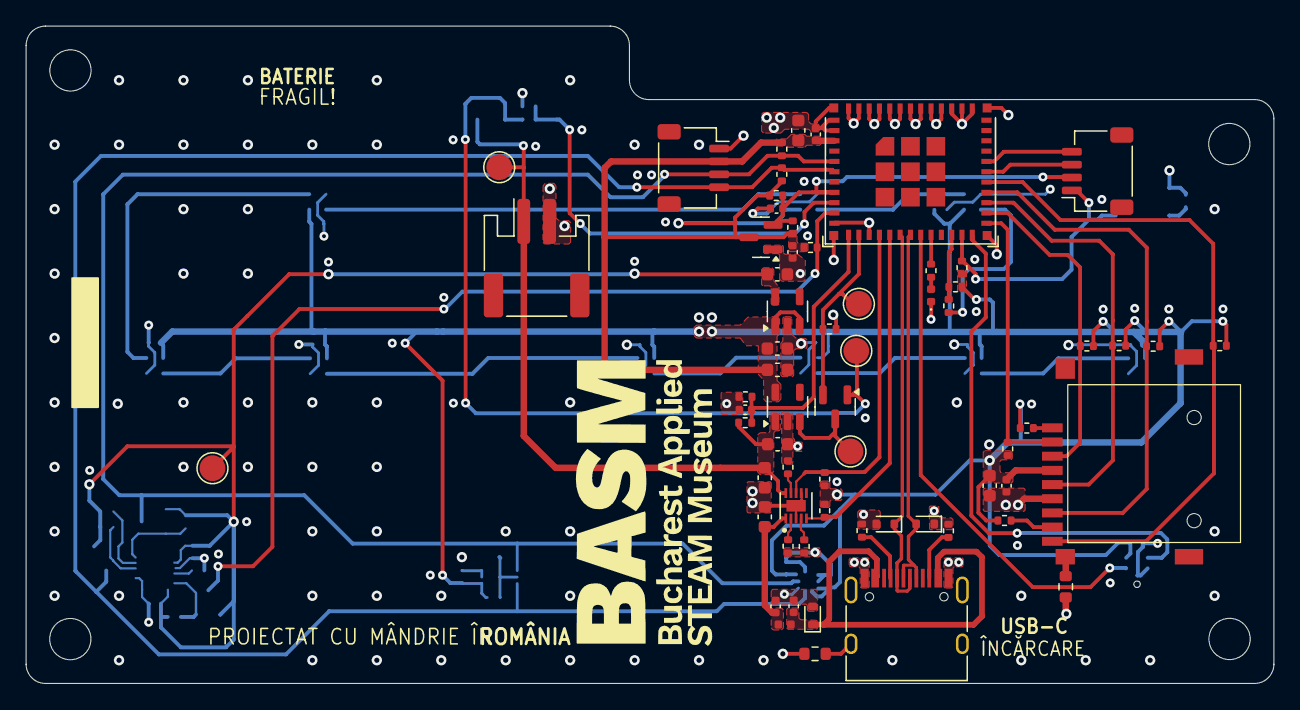
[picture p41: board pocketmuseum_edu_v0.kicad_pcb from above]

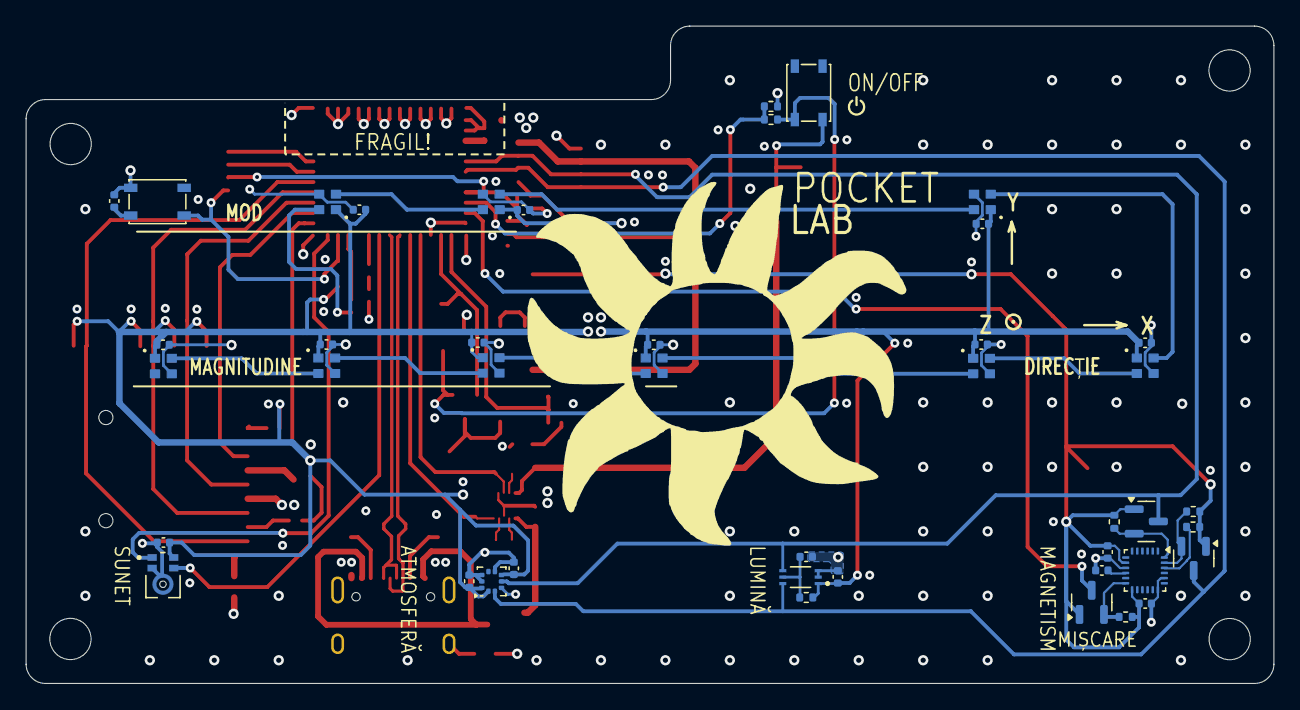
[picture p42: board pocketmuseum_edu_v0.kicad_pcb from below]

Board: 4 copper layers, 96.8 x 51.0 mm, 111 parts (43 on the bottom side), 56 nets.

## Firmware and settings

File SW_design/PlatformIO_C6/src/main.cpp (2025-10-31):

#include <Arduino.h>
#include "sensors/SensorTask.h"
#include "display/DisplayTask.h"
#include "audio/AudioTask.h"
#include "storage/SDManager.h"
#include "power/BMSTask.h"
#include "evaluators/EvaluatorTask.h"
#include "network/NetworkTask.h"
#include "shared_resources/SharedDataBuffer.h"
#include "shared_resources/globals.h"
#include "shared_resources/global_debug.h"

SensorTask sensorTask;
SDManager sDManager;
AudioTask audioTask;
EvaluatorTask evaluatorTask(sDManager); 
DisplayTask displayTask;
BMSTask bmsTask;
NetworkTask networkTask;

// Task handles for monitoring
TaskHandle_t sensorHandle, displayHandle, audioHandle, bmsHandle, evaluatorHandle, networkHandle;

void setup() {
    Serial.begin(115200);

    // Initialize Shared Data Buffer & MUTEX protection
    SharedBuffer::init();

    // Initialize all State Machines
    bmsTask.setupBMSTask();
    displayTask.setupDisplayTask(&bmsTask);
    sensorTask.setupSensorTask(&bmsTask);
    evaluatorTask.setupEvaluatorTask(displayTask);
    audioTask.setupAudioTask(&bmsTask);
    sDManager.setupSDManager();
    networkTask.setup(&bmsTask);

    // Create FreeRTOS tasks
    xTaskCreatePinnedToCore(DisplayTask::runDisplayTaskWrapper, "DisplayTask", 4096, &displayTask, 4, &displayHandle, 0);
    xTaskCreatePinnedToCore(BMSTask::runBMSTaskWrapper, "BMSTask", 4096, &bmsTask, 5, &bmsHandle, 0);
    xTaskCreatePinnedToCore(SensorTask::runSensorTaskWrapper, "SensorTask", 4096, &sensorTask, 1, &sensorHandle, 0);
    xTaskCreatePinnedToCore(SDManager::runSDManagerWrapper, "SDManager", 4096, &sDManager, 6, nullptr, 0);
    xTaskCreatePinnedToCore(EvaluatorTask::runEvaluatorTaskWrapper, "EvaluatorTask", 4096, &evaluatorTask, 3, &evaluatorHandle, 0);
    xTaskCreatePinnedToCore(AudioTask::runAudioTaskWrapper, "AudioTask", 4096, &audioTask, 2, &audioHandle, 0);
    xTaskCreatePinnedToCore(NetworkTask::runNetworkTaskWrapper, "NetworkTask", 8192, &networkTask, 7, &networkHandle, 0);
}

void loop() {
    static unsigned long lastPrint = 0;
    const unsigned long interval = 10000; // 10 seconds

    if (millis() - lastPrint >= interval) {
        lastPrint = millis();

        char statsBuf[2048];

        RATES_PRINTLN("======================================");
        RATES_PRINTLN("FreeRTOS Task Runtime Stats:");
        vTaskGetRunTimeStats(statsBuf); // CPU usage
        RATES_PRINTLN(statsBuf);

        RATES_PRINTLN("FreeRTOS Task List (State, Prio, Stack, Task#):");
        vTaskList(statsBuf); // Task states
        RATES_PRINTLN(statsBuf);

        // Print stack high-water mark for each task
        RATES_PRINTF("[SensorTask]      Stack high-water mark: %u words\n", uxTaskGetStackHighWaterMark(sensorHandle));
        RATES_PRINTF("[DisplayTask]     Stack high-water mark: %u words\n", uxTaskGetStackHighWaterMark(displayHandle));
        RATES_PRINTF("[AudioTask]       Stack high-water mark: %u words\n", uxTaskGetStackHighWaterMark(audioHandle));
        RATES_PRINTF("[BMSTask]         Stack high-water mark: %u words\n", uxTaskGetStackHighWaterMark(bmsHandle));
        RATES_PRINTF("[EvaluatorTask]   Stack high-water mark: %u words\n", uxTaskGetStackHighWaterMark(evaluatorHandle));
        RATES_PRINTF("[NetworkTask]     Stack high-water mark: %u words\n", uxTaskGetStackHighWaterMark(networkHandle));

        RATES_PRINTLN("======================================\n");
    }

    delay(10000 - 500);
}

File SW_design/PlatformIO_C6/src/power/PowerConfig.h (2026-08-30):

// CONFIGURATION PARAMETERS FOR THE POWER SYSTEM

// [BMS] ChargeController and Feedback
#define VBAT_VTHRESHOLD             3.4f// If the system is predicted to reach VBAT_VTHRESHOLD within VBAT_TIME_TO_VTHRESHOLD_MIN, LOW_POWER will be indicated
#define VBAT_TIME_TO_VTHRESHOLD_MIN 15.0f
#define VBAT_SETTLING_PERIOD_SEC    90.0f// To avoid LiPo transients, within VBAT_SETTLING_PERIOD_SEC from transitioning to BATT_ONLY, no LOW_BATT predictions are made
#define VBAT_CHECK_INTERVAL_SEC     10.0f// [s] - sample Battery voltage every X seconds
#define VBAT_HISTORY_LEN            60   // number of samples in VBat History
#define VBAT_AVG_SAMPLES            4    // Number of averaged ADC readings per sample
#define VBAT_MIN_VOLTAGE            2.85f// Acceptable physical range for battery voltage (Volts) - MAX
#define VBAT_MAX_VOLTAGE            4.30f// Acceptable physical range for battery voltage (Volts) - MIN

// ===================== BMSTask ==================== //
#define BMS_LDO_ATTACH_CMD_PIN      1
#define BMS_ONOFF_PUSHBUTTON_PIN    4
#define BMS_TIMER_STARTUP           2200 // [ms] - HOLD ON/OFF pressed before latching ON
#define BMS_TIMER_SHUTDOWN          2200 // [ms] - HOLD ON/OFF pressed before latching OFF


// ================ ChargeController ================ //
#define BMS_CHG_FDBCK_PIN           6
#define BMS_POWOK_FDBCK_PIN         7

// ================== SoCController ================= //
#define BMS_VBAT_VOLT_PIN           0
#define VBAT_DIVIDER_RTOP           178e3f
#define VBAT_DIVIDER_RBOTTOM        61.9e3f
#define ADC_CORRECTION_SLOPE        0.9796f // ACTUAL_VOLTAGE = ADC_CORRECTION_SLOPE * ADC_MEASURED_VOLTAGE + ADC_CORRECTION_OFFSET
#define ADC_CORRECTION_OFFSET       0.0548f // ACTUAL_VOLTAGE = ADC_CORRECTION_SLOPE * ADC_MEASURED_VOLTAGE + ADC_CORRECTION_OFFSET
#define EMA_ALPHA                   0.004 // Computed for a time_constant of approx. 5 sec [α = 1 - exp(-dt / τ)]
#define VBAT_MIN_VOLTAGE            2.85f // Acceptable physical range for battery voltage (Volts) - MAX
#define VBAT_MAX_VOLTAGE            4.30f // Acceptable physical range for battery voltage (Volts) - MIN

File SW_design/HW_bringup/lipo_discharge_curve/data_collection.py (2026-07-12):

from saleae import automation
import os
import os.path
import csv
import re
import shutil
import time
import serial
import matplotlib.pyplot as plt
from datetime import datetime

DEVICE_ID = 'ECCE3A142D5FF009'
ANALOG_CHANNELS = [4, 5]
SAMPLE_RATE = 50            # Sa/s
CAPTURE_DURATION_S = 0.5    # seconds per capture

SERIAL_PORT = '/dev/ttyACM0'
SERIAL_BAUDRATE = 115200    # adjust if your firmware uses a different rate
SERIAL_READ_TIMEOUT_S = 1   # how long each ser.readline() call blocks at most
IDLE_TIMEOUT_S = 30         # stop the program if no valid message arrives within this window

# Matches lines like: "p-l-vbat: 12.345,11.987"
VBAT_LINE_RE = re.compile(r"^p-l-vbat:\s*(-?\d+(?:\.\d+)?),(-?\d+(?:\.\d+)?)\s*$")

# Current / capacity computation parameters
OFFSET = 0.0          # V, sensor offset
R = 1.0               # ohms, shunt resistance
CAPACITY_TOTAL_MAH = 500.0

# Where to stage exports temporarily before deleting them. Reused every
# iteration so we don't leave thousands of folders behind.
TEMP_EXPORT_DIR = os.path.join(os.getcwd(), "capture_export_tmp")

# Persistent log file that accumulates results across all triggers (this one
# is NOT deleted, since it's the actual data we care about keeping).
LOG_FILE_PATH = os.path.join(os.getcwd(), "vbat_capture_log.csv")


def read_channel_averages(csv_path, channels):
    """Read the combined analog.csv (one column per channel, plus a time
    column) and return {channel: average} across all rows."""
    sums = {ch: 0.0 for ch in channels}
    count = 0

    with open(csv_path, newline='') as f:
        reader = csv.reader(f)
        header = next(reader)  # e.g. ["Time [s]", "Channel 4", "Channel 5"]

        col_index = {}
        for ch in channels:
            for i, col_name in enumerate(header):
                if col_name.strip().lower() == f"channel {ch}":
                    col_index[ch] = i
                    break
            else:
                raise ValueError(f"Could not find column for channel {ch} in header: {header}")

        for row in reader:
            for ch in channels:
                sums[ch] += float(row[col_index[ch]])
            count += 1

    averages = {ch: (sums[ch] / count if count > 0 else float('nan')) for ch in channels}
    return averages, count


def ensure_log_header():
    if not os.path.exists(LOG_FILE_PATH):
        with open(LOG_FILE_PATH, 'w', newline='') as f:
            writer = csv.writer(f)
            header = ["timestamp", "elapsed_s", "last_sample", "vbat_history_back"]
            header += [f"ch{ch}_avg_V" for ch in ANALOG_CHANNELS]
            header += ["current_computed_mA", "capacity_used_mAh"]
            writer.writerow(header)


def run_capture_and_average(manager, device_configuration, capture_configuration):
    """Runs a single 0.5s capture, exports it, computes per-channel averages,
    cleans up the export, and returns {channel: average}."""
    with manager.start_capture(
        device_id=DEVICE_ID,
        device_configuration=device_configuration,
        capture_configuration=capture_configuration) as capture:

        capture.wait()

        os.makedirs(TEMP_EXPORT_DIR, exist_ok=True)
        capture.export_raw_data_csv(
            directory=TEMP_EXPORT_DIR,
            analog_channels=ANALOG_CHANNELS,
        )

        csv_path = os.path.join(TEMP_EXPORT_DIR, "analog.csv")
        if not os.path.exists(csv_path):
            print(f"Warning: expected export file not found: {csv_path}")
            channel_averages = {ch: float('nan') for ch in ANALOG_CHANNELS}
        else:
            channel_averages, _ = read_channel_averages(csv_path, ANALOG_CHANNELS)

    shutil.rmtree(TEMP_EXPORT_DIR, ignore_errors=True)
    return channel_averages


class LivePlot:
    """Maintains a 2x2 grid of subplots, updated as new samples arrive."""

    def __init__(self):
        plt.ion()
        self.fig, self.axs = plt.subplots(2, 2, figsize=(10, 8))
        self.fig.suptitle("LiPo Discharge Curve - Live")

        self.t = []
        self.ch4 = []
        self.ch5 = []
        self.vbat_history_back = []
        self.current_computed = []
        self.capacity_used = []

        self._configure_axes()
        self.fig.tight_layout(rect=[0, 0, 1, 0.96])
        plt.show(block=False)

    def _configure_axes(self):
        ax = self.axs[0, 0]
        ax.set_title("VBAT history vs Ch5")
        ax.set_xlabel("Ch5 (V)")
        ax.set_ylabel("vbat_history_back")

        ax = self.axs[0, 1]
        ax.set_title("Current vs Time")
        ax.set_xlabel("Time (s)")
        ax.set_ylabel("Current (mA)")

        ax = self.axs[1, 0]
        ax.set_title("Capacity Used vs Time")
        ax.set_xlabel("Time (s)")
        ax.set_ylabel("Capacity used (mAh)")

        ax = self.axs[1, 1]
        ax.set_title("Battery Voltage vs State of Charge")
        ax.set_xlabel("SoC (%)")
        ax.set_ylabel("Battery Voltage (mV)")
        ax.set_xlim(100, 0)

    def add_sample(self, t, ch4, ch5, vbat_history_back, current_computed, capacity_used):
        self.t.append(t)
        self.ch4.append(ch4)
        self.ch5.append(ch5)
        self.vbat_history_back.append(vbat_history_back)
        self.current_computed.append(current_computed)
        self.capacity_used.append(capacity_used)
        self._redraw()

    def _redraw(self):
        for ax_row in self.axs:
            for ax in ax_row:
                ax.clear()
        self._configure_axes()

        self.axs[0, 0].scatter(self.ch5, self.vbat_history_back, s=15, color='tab:blue')

        self.axs[0, 1].plot(self.t, self.current_computed, color='tab:orange')

        self.axs[1, 0].plot(self.t, self.capacity_used, color='tab:green')

        soc_percent = [(CAPACITY_TOTAL_MAH - c) / CAPACITY_TOTAL_MAH * 100.0 for c in self.capacity_used]
        ch4_mV = [v * 1000.0 for v in self.ch4]
        self.axs[1, 1].scatter(soc_percent, ch4_mV, s=15, color='tab:red')

        self.fig.canvas.draw()
        self.fig.canvas.flush_events()
        plt.pause(0.001)
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

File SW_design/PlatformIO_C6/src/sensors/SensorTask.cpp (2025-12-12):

#include "sensors/SensorTask.h"
#include "sensors/ICP201XXHAL.h"
#include "sensors/ICM209XXHAL.h"
#include "sensors/BH1750HAL.h"
#include "sensors/AS7343HAL.h"
#include "sensors/AS7331HAL.h"
#include "sensors/AMG88XXHAL.h"
#include "sensors/SensorHAL.h"
#include "shared_resources/SharedDataBuffer.h"
#include "shared_resources/globals.h"
#include "shared_resources/global_functions.h"
#include "shared_resources/global_debug.h"

#include <Wire.h>


// TO DO: IN RUN_READ, GUARD AGANST STALE READINGS FROM SENSORS


// Instantiate ICP20100 HAL Wrapper
ICP201XXHAL pressureSensor(Wire);

// Instantiate BH1750FVI HAL Wrapper
BH1750HAL lightSensor(Wire);

// Instantiate ICM20948 HAL Wrapper
ICM209XXHAL imuSensor(Wire);

// Instantiate AS7343 HAL Wrapper (Spectral Sensor)
AS7343HAL spectralSensor(Wire);

// Instantiate AS7331 HAL Wrapper (Spectral UV Sensor)
AS7331HAL spectralUVSensor(Wire);

// Instantiate AMG88XX HAL Wrapper (Thermal Sensor)
AMG88XXHAL thermalSensor(Wire);

// CLASS Constructor
SensorTask::SensorTask() {}

void SensorTask::setupSensorTask(BMSTask* bms) {
    setSensorState(SensorState::BOOT);
    // Set BMSTask pointer
    this->bmsTask = bms;
}

void SensorTask::setSensorState(SensorState new_state) {
    // Optional: Add safety checks or mutex here
    current_state = new_state;
}

void SensorTask::runSensorTaskWrapper(void* param) {
    SensorTask* self = static_cast<SensorTask*>(param);

    TickType_t lastWakeTime = xTaskGetTickCount();
    const TickType_t frequency = pdMS_TO_TICKS(1000 / TASK_RATE_SENSOR);

    for (;;) {
        self->runSensorTask();
        vTaskDelayUntil(&lastWakeTime, frequency);
    }
}

void SensorTask::runSensorTask() {
    switch (current_state) {
        case SensorState::BOOT:{
            run_boot();
            break;
        }
        case SensorState::INIT:{
            run_init();
            break;
        }
        case SensorState::SLEEP:{
            run_sleep();
            break;
        }
        case SensorState::READ:{
            run_read();
            break;
        }
        case SensorState::PROCESS:{
            run_process();
            break;
        }
    }  
    // Print frequency every 1 second
    #if DEBUG_TASK_RATES
        // Increment the read count
        updateCount++;
        unsigned long now = millis();
        if (now - lastFreqPrintTime >= 10000) {
            state_machine_run_freq = updateCount / ((now - lastFreqPrintTime) / 1000.0f); // Hz
            RATES_PRINT("[SensorTask] Actual update frequency: ");
            RATES_PRINT(state_machine_run_freq);
            RATES_PRINTLN(" Hz");

            // Reset counters
            updateCount = 0;
            lastFreqPrintTime = now;
        }
    #endif  
}

// ======== STATE METHODS ==========

void SensorTask::run_boot(){
    // Check if BMS is Ready
    if (bmsTask && bmsTask->isLatched()) {
        // Transition to INIT
        setSensorState(SensorState::INIT);
    }
};

void SensorTask::run_init(){
    // ✅ DEBUG: Print StateMachine State Change
    Serial.println("[SensorTask] - Configuring sensors...");
    // SENSOR I2C BUS INIT.
    Wire.begin(I2C_SDA_PIN, I2C_SCL_PIN);
    Wire.setClock(I2C_BITRATE);

    // ICP20100 SENSOR ; I2C Address - 0x63
    if (pressureSensor.begin()){
        pressureSensor.setReadFrequency(SENSOR_RATE_BARO);
        Serial.println("[SensorTask] - ICP20100 initialized successfully");
    }

    // BH1750FVI SENSOR ; I2C Address - 0x23
    if (lightSensor.begin()){
        lightSensor.setReadFrequency(SENSOR_RATE_AMB_LUX);
        Serial.println("[SensorTask] - BH1750FVI initialized successfully");
    }

    // ICM20948 SENSOR ; I2C Address - 0x68
    if (imuSensor.begin()){
        imuSensor.setReadFrequency(SENSOR_RATE_IMU);
        Serial.println("[SensorTask] - ICM20948 initialized successfully");
    }

    // AS7343 SPECTRAL SENSOR ; I2C Address - 0x39 (Optional - may or may not be attached)
    if (spectralSensor.begin()){
        spectralSensor.setReadFrequency(SENSOR_RATE_SPECTRAL);
        Serial.println("[SensorTask] - AS7343 initialized successfully");
    } else {
        Serial.println("[SensorTask] - AS7343 not detected (optional sensor)");
    }

    // AS7331 SPECTRAL UV SENSOR ; I2C Address - 0x74 (Optional - may or may not be attached)
    if (spectralUVSensor.begin()){
        spectralUVSensor.setReadFrequency(SENSOR_RATE_SPECTRAL_UV);
        Serial.println("[SensorTask] - AS7331 initialized successfully");
    } else {
        Serial.println("[SensorTask] - AS7331 not detected (optional sensor)");
    }

    // AMG88XX THERMAL SENSOR ; I2C Address - 0x69 (Optional - may or may not be attached)
    if (thermalSensor.begin()){
        thermalSensor.setReadFrequency(SENSOR_RATE_GRIDEYE);
        Serial.println("[SensorTask] - AMG88XX initialized successfully");
    } else {
        Serial.println("[SensorTask] - AMG88XX not detected (optional sensor)");
    }

    delay(1000);
    // Carry on to READ State
    setSensorState(SensorState::READ);
};
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

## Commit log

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2025-07-19 Added Resettable Aggregate data to SharedDataBuffer
    [DisplayTask.cpp, SDManager.cpp, SensorHAL.h]
2025-07-19 Added initialization of button to fix rising-edge on BOOT
    [DisplayTask.cpp]
2025-07-23 Issue with SDManager Cue timing
    [DisplayTask.cpp, EvaluatorTask.cpp, SDManager.cpp]
2025-07-31 [EDU_V0] Swapped 6DOF IMU for 9DOF IMU
    [Feddback.kicad_sch, MCU.kicad_sch, Power.kicad_sch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]
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2025-08-27 Fixed EDUV0 Missing Mask
    [pocketmuseum_edu_v0-CuBottom.gbr, pocketmuseum_edu_v0-CuIn1.gbr, pocketmuseum_edu_v0-CuIn2.gbr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]
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2025-10-02 Reverted MAIN to pre-NC build
    [EvaluatorTask.cpp, SensorTask.cpp, globals.h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]
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2025-10-05 Added ChargeController & Fixed transient & spurrios bugs
    [BMSTask.cpp, DisplayTask.cpp, SensorTask.cpp]
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2025-10-28 Implemented variable-sensor rates & new SharedBuffer - BUG Active
    [SensorHAL.h, SensorTask.cpp]
2025-10-30 Bug-semi-fixed - still inconsistent but decent HW limitation maybe
    [SensorTask.cpp, globals.h]
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2025-10-30 Initialize AS7343 spectral sensor fields and volume_rms with NAN
    Changes all AS7343 spectral sensor fields from uint16_t to float and
    initializes them with NAN for proper auto-exclusion in network packets.
    Also fixes uninitialized volume_rms field.
    - Convert all 14 spectral fields from uint16_t to float type
    - Initialize all spectral fields with NAN instead of 0
    - Initialize volume_rms with NAN (was uninitialized)
    - Update NetworkTask JSON formatting to check individual spectral
    fields for NAN values before including them
    - Format spectral values as integers (cast to int) since they are
    ADC counts despite being stored as floats
    - Add NAN check for volume_rms in JSON formatting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
    [NetworkTask.cpp]
2025-10-30 Refactor NetworkTask: Add BMS latching, remove DHCP, simplify config
    This commit addresses several improvements to NetworkTask based on
    user feedback to align with existing task patterns and simplify
    configuration.
    1. Add BMS Latching Check (matching AudioTask pattern):
    - NetworkTask.h: Add BMSTask* bmsTask member and include BMSTask.h
    - NetworkTask.cpp: Update setup() to accept BMSTask* parameter
    - run_boot(): Only transition to INIT when bmsTask->isLatched()
    - main.cpp: Pass &bmsTask to networkTask.setup()
    - Ensures WiFi doesn't initialize until power is stable
    2. Remove NETWORK_DATA_SEND_RATE_HZ (decouple from TASK_RATE_NETWORK):
    - Remove separate data send r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
    [NetworkTask.cpp, globals.h, main.cpp]
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2025-10-31 Fix SocketIO async mode to use threading instead of eventlet
    Changed Flask-SocketIO to use threading mode by default, which doesn't
    require additional dependencies like eventlet. This fixes the
    "Invalid async_mode specified" error.
    - app.py: Changed async_mode from 'eventlet' to 'threading'
    - requirements.txt: Made eventlet optional with installation notes
    Threading mode is sufficient for the dashboard's needs and works
    out-of-the-box with Flask-SocketIO. For production deployments
    needing higher performance, eventlet or gevent can be optionally
    installed and will be auto-detected.
    Fixes error: ValueError: Invalid async_mode specified
    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
2025-11-01 Add Pocket Lab Data tab interactive mockup with all display types
    Created a fully functional mockup to demonstrate the complete user flow
    for the Pocket Lab Data tab. Uses mock data generation to simulate
    real-time ESP32 sensor readings.
    User Flow:
    1. Device Selection - Choose from 4 mock ESP32 devices
    2. Measurement Selection - Pick sensors and display types
    3. Live Display - See real-time mock data in various formats
    Display Types Implemented:
    - Numeric Only: Last value with large text display
    - Numeric w. Statistics: Min/Max/Avg/StdDev/Count with reset
    - Time-graph: 10-second scrolling window with auto-scaling
    - Vector quantities show all components (X, Y, Z, Norm) with legend
    - Vecto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
2025-11-02 Implement custom SVG icons and color-coding for Pocket Lab mockup
    - Add 8 custom SVG icons for all measurement types (temperature, pressure, acceleration, gyro, magnetometer, volume, ambient light, spectrum)
    - Define MEASUREMENT_COLORS with specific colors: RED, BLUE, GREEN, ORANGE, YELLOW, PINK, WHITE, PURPLE
    - Apply color-coding to both measurement selector cards and active display cards
    - Add comprehensive debug logging throughout initialization and chart creation
    - Increase chart initialization timeout from 100ms to 200ms for better reliability
    - Update Chart.js datasets to use measurement-specific colors
    - Add Chart.js availability checks with error logging
    Addresses user feedback on i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
2025-11-02 Fix offline resource loading for Raspberry Pi dashboard
    The dashboard was failing to load Chart.js and other CDN resources because the Raspberry Pi has no internet connectivity when acting as an access point. This was causing:
    - 15+ second page load times
    - Chart.js not loading errors
    - Charts/graphs not rendering
    - Update HTML to use local resource paths instead of CDNs
    - Remove Google Fonts dependency (use system fonts)
    - Change Bootstrap Icons to local path
    - Change Chart.js to local path
    - Create download script (download_offline_resources.sh) to fetch resources on a machine with internet
    - Add comprehensive setup documentation (SETUP_OFFLINE_RESOURCES.md)
    - Add README files in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
2025-11-02 Improve mockup UI: blue reset button, larger X button, fix ambient light color
    Changes requested by user:
    1. Change Reset Statistics button from pink to blue (matches other buttons)
    2. Enlarge and thicken X close button by 50% (32px -> 48px, font-weight 700)
    3. Fix white text on white background for ambient light by changing color from #ffffff to #fbbf24 (bright amber/gold) - better represents light and is visible on all backgrounds
    These changes improve usability and visual consistency.
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2025-11-02 Add Socket.IO to offline resources (fixes live dashboard)
    The live dashboard was failing to load Socket.IO from CDN, causing:
    - "Socket.IO not loaded! Live data will not work" error
    - WebSocket connection failures
    - No real-time ESP32 data
    - Update download_offline_resources.sh to download Socket.IO (59KB)
    - Change pocket-lab-live.html to use local /js/socket.io.min.js
    - Update SETUP_OFFLINE_RESOURCES.md with Socket.IO instructions
    - Add Socket.IO to verification steps
    After running the download script, the live dashboard will:
    ✅ Load Socket.IO from local file
    ✅ Establish WebSocket connection
    ✅ Receive real-time ESP32 sensor data
    Users must re-run: bash raspberry_pi_dashboa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
2025-11-02 Complete live dashboard WebSocket integration and sensor data mapping
    Fixed and implemented:
    1. API response parsing - handle { "devices": [...] } format correctly
    2. Device selection - use node_id and hostname from API
    3. WebSocket room subscription when device selected
    4. Complete handleSensorData() function to process incoming packets
    5. extractSensorValue() mapper for all 8 measurement types:
    - temperature → data.temperature
    - pressure → data.pressure
    - acceleration → accel_x/y/z/norm
    - gyro → gyro_x/y/z/norm
    - magnetometer → mag_x/y/z/norm
    - volume → volume_rms
    - ambientLight → light_intensity
    - spectrum → 12 spectral channels mapped to chart form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
2025-11-02 Fix live dashboard: flickering, mock data, unavailable sensors, slow loading
    Fixed 5 critical issues reported by user:
    1. Device Card Flickering (FIXED)
    - Problem: Card flickered violently when clicked
    - Root cause: updateDeviceStatus() called renderDeviceGrid() on EVERY UDP packet
    - Solution: Removed constant re-rendering, only update device data in memory
    2. Mock Data Still Showing (FIXED)
    - Problem: Displays showed random data, not real ESP32 data
    - Root cause: startDataUpdates() was generating mock data with setInterval
    - Solution: Completely removed mock data generation, displays now show only WebSocket data
    - Displays initialize with "--" and "Waiting for live da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
2025-11-02 Fix WebSocket subscription: live sensor data now displays correctly
    CRITICAL FIX: Resolved issue where sensor data showed nil/dashes
    Root cause: Frontend emitted 'join' event but backend listened for 'subscribe_device'
    - Changed selectDevice() to emit 'subscribe_device' with {node_id: ...}
    - Backend now properly adds client to room 'device_{node_id}'
    - Sensor data broadcasts now reach the subscribed client
    Added comprehensive debug logging:
    - Log WebSocket subscription attempts and confirmations
    - Log all sensor_data events received
    - Log data extraction and display updates
    - Log which displays are active when data arrives
    This fixes the critical issue where dashboard responded to ESP32 o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
2025-11-03 Improve UI: theme-aware buttons, larger close button, ambient light contrast
    1. Applied measurement-specific colors to numeric displays (already done)
    - Numeric Only cards now show values in their measurement colors
    - Temperature: red, Pressure: blue, Acceleration: green, etc.
    2. Made Reset Statistics button theme-aware
    - Blue border/text in light theme
    - White border/text in dark theme
    - Added new .btn-outline-theme-reset class
    3. Enlarged and emboldened red X close button
    - Increased from 48px to 56px (width & height)
    - Increased font-size from 1.5rem to 2rem
    - Increased font-weight from 700 to 900 (boldest)
    4. Fixed Ambient Light contrast issue in light theme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
2025-11-03 Add comprehensive backend logging to debug UDP→WebSocket data flow
    Problem: tcpdump shows real ESP32 packets but dashboard shows fake data
    This suggests data corruption or transformation somewhere in the pipeline:
    ESP32 → UDP port 5000 → udp_listener.py → Database → WebSocket → Frontend
    Added detailed logging at each stage:
    1. UDP Packet Reception:
    📦 RAW UDP PACKET from 192.168.10.11: {json...}
    - Logs the exact JSON string received from ESP32
    - Before any parsing or database operations
    2. WebSocket Broadcast Preparation:
    📡 BROADCASTING to WebSocket for 192.168.10.11: {data...}
    - Logs the exact data being sent to WebSocket
    - After database round-trip via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
2025-11-04 Remove all mock data generation and add comprehensive WebSocket event logging
    Problem: Backend shows real data but frontend shows fake data
    Root cause investigation needed
    1. Removed generateMockValue() function entirely (unused dead code)
    2. Removed AppState.mockDataGenerators (no longer needed)
    3. Added socket.onAny() to log ALL WebSocket events received
    4. Added RAW WEBSOCKET PAYLOAD logging for sensor_data events
    5. Shows full JSON payload as received from WebSocket
    This will reveal if:
    - WebSocket events are being received at all
    - The payload contains real or fake data
    - Events are being dropped or filtered
    Expected browser console output:
    🔔 WebSocket event: "sensor_data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
2025-11-04 Optimize performance: rate-limit debug logging to prevent browser slowdown
    Problem: Browser performance degraded after a few seconds
    Root cause: Excessive debug logging at 25 Hz (50+ messages/sec) overwhelmed browser console
    Solution: Rate-limited verbose logging while keeping data updates at full 25 Hz
    1. Added debugLogCounter and lastDebugLog to AppState
    2. Log sensor_data events only every 25th message (1/sec instead of 25/sec)
    3. Removed per-update logging from handleSensorData()
    4. Removed all verbose logging from updateChart() (called 25x/sec)
    5. Removed per-display logging from updateDisplay()
    6. Kept essential logs: connection, subscription, first packet, errors
    Performan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
2025-11-04 Fix Time Window: implement proper accumulation and sliding window behavior
    Problem: Time Window selector didn't work correctly
    - X-axis didn't freeze at start when increasing time scale
    - Data was immediately pruned instead of accumulating
    - Changing time scale cleared all data
    Expected behavior (now implemented):
    1. Accumulation Phase (0 to timeScale seconds):
    - X-axis fixed at [0, timeScale] (e.g., 0 to 10s)
    - Data accumulates from time 0 onwards
    - Chart fills up gradually
    2. Sliding Window Phase (after timeScale seconds):
    - X-axis slides to show [currentTime - timeScale, currentTime]
    - Oldest data outside window is pruned
    - Chart shows most recent timeScale seconds
    3.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
2025-11-04 UI improvements: Hz indicator, badge sizing, close button, device cards
    1. Moved Hz indicator from top-right to bottom-left
    - Removed from display header (line 680 in pocket-lab-live.js)
    - Added to chart-info div (replaces "Last X seconds")
    - Now appears bottom-left for all Time-graph displays
    - Shows real-time update rate (e.g., "25.0 Hz")
    2. Adjusted display type badge font size
    - Reduced from 0.75rem to 0.65rem
    - Reduced padding from 0.25rem to 0.2rem
    - Added white-space: nowrap to prevent wrapping
    - "Numeric w. Statistics" now fits on single line
    3. Made close button (X) 20% smaller
    - Reduced from 56px to 45px (width & height)
    - Reduced font-size from 2rem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
2025-11-04 Fix performance degradation with multiple ESP32s and center badge text
    Performance fix:
    - Rate-limit device_status broadcasts to 1 Hz per device (was 25 Hz)
    - Prevents WebSocket event storm when multiple ESP32s stream simultaneously
    - With 2 ESP32s, reduces total events from ~75 Hz to ~27 Hz per client
    - Maintains full 25 Hz sensor_data update rate for displays
    UI fix:
    - Center display type badge text both vertically and horizontally
    - Added flexbox centering (inline-flex, align-items, justify-content)
    Files modified:
    - raspberry_pi_dashboard/udp_listener.py: Added last_status_broadcast tracking
    - raspberry_pi_dashboard/static/css/pocket-lab-mockup.css: Badge centering
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2025-11-04 Fix performance degradation by eliminating excessive backend logging
    Problem:
    With 2 ESP32s streaming at 25 Hz each (50 packets/sec total), excessive
    logging was causing severe performance issues:
    - 3 log messages per packet = 150 log messages/sec
    - Terminal output buffer was overwhelming the system
    - Display update rates dropped by 30-40% with multiple ESP32s connected
    Solution:
    Implemented rate-limited summary logging at 0.2 Hz (every 5 seconds):
    - Added packet_counts tracker per device
    - New _log_summary_stats() method prints aggregated packet rates
    - Example output: "📊 UDP Packet Rates: LAB_01: 25.2 Hz (126 packets) | LAB_02: 24.8 Hz (124 packets)"
    - Removed verbose per-packet logs: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
2025-11-04 Fix database I/O bottleneck causing 40% packet loss with multiple ESP32s
    Root cause analysis:
    - tcpdump confirmed packets arrive at 25 Hz per ESP32 (as expected)
    - Backend only processes at ~15 Hz per ESP32 (40% loss)
    - Bottleneck: db.session.commit() called after EVERY packet
    - With 2 ESP32s: 50 packets/sec = 50 synchronous SQLite commits/sec
    - Each commit: fsync(), journal operations, lock acquire/release
    - On Raspberry Pi SD card: ~25ms per commit
    - Total blocking time: 50 × 25ms = 1250ms per second (125% overload)
    - UDP receive buffer fills up, packets delayed/dropped
    Solution - Batched database commits:
    - Commit every 10 packets OR every 100ms (whichever comes first)
    - Reduces commits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
2025-11-04 Fix UI freezing by throttling rendering to 13 Hz and caching timestamps
    User reported Active Data Display cards freeze every few seconds, with data
    appearing to "jump" when unfreezing. Issue worsened after recent commits.
    Root causes identified:
    1. Rendering at 25 Hz causes excessive DOM operations:
    - chart.update('none') - still blocks UI thread even without animations
    - Multiple getElementById calls per update
    - textContent updates blocking main thread
    - With 3 displays: 75 render operations/sec → UI freezes
    2. new Date().toLocaleTimeString() called 25x/sec per display:
    - Extremely expensive operation (locale-specific date formatting)
    - With 3 displays: 75 ex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
2025-11-05 Fix data loss in charts, UI improvements, and acceleration scaling
    Issue 1: Data loss during UI freezes (CRITICAL FIX)
    Problem: Throttling was implemented at wrong level - returned early from
    updateDisplay(), which prevented updateChart() from being called. This meant
    data points were never added to charts, causing visible gaps and "jumping"
    when unfreezing.
    Solution: Moved throttling inside updateChart()
    - Data points are ALWAYS added to chart.data (lines 1321-1330)
    - Only chart.update() call is throttled to 13 Hz (line 1366-1369)
    - No data loss, but still prevents UI freezing
    - Charts show smooth continuous data at 13 Hz render rate
    Issue 2: Display type badges too tall
    - Reduced vertica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
2025-11-05 Support unlimited ESP32s, improve device header, fix ambient light badge text
    Issue 1: ESP32 IP range support
    - System already supports any number of ESP32s (11-111 and beyond)
    - Devices self-register via UDP when they send first packet
    - No hardcoded IP restrictions in codebase
    - Backend dynamically creates Device records for any node_id
    Issue 2: Device header improvements after ESP32 selection
    Before:
    - IC clipart icon (bi-cpu-fill)
    - Device hostname in h3
    - Device ID in smaller text below
    After:
    - Custom pocket-lab-icon.png (48x48px)
    - Device ID shown once in large h3
    - Removed duplicate small ID text
    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
2025-11-09 Add separate LED mappings for VU and binary display modes
    - Created LED_MAPPING_VU and LED_MAPPING_BINARY arrays
    - VU mode: 2 mode + 1 direction (INOP) + 6 magnitude LEDs
    - Binary mode: 2 mode + 3 direction (X,Y,Z) + 4 magnitude LEDs
    - Updated setLogicalPixel to use correct mapping based on display_mode
    - Updated turnDisplayOFF to handle both LED counts
    [DisplayTask.cpp]
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2025-11-09 Cache scaling coefficients to avoid switch statements at 50Hz
    - Added cached member variables: vu_min_value, vu_max_value, binary_mag_order, binary_dir_norm
    - Created loadScalingCoefficients() to load all coefficients once per state change
    - Called loadScalingCoefficients() in cycleDisplayState() and run_init()
    - Simplified updateMagnitudeDisplay() and updateDirectionDisplay() to use cached values
    - Reduces switch statement execution from 50Hz to ~1Hz (only when cycling states)
    - Significant performance optimization with no functional change
    [DisplayTask.cpp]
2025-11-09 Reverse binary LED ordering and swap bit-to-color mapping
    Binary magnitude display changes:
    - Leftmost LED (physical 8) now shows MSB (bits 11,10,9)
    - Rightmost LED (physical 5) now shows LSB (bits 2,1,0)
    - Within each LED, bit-to-color mapping:
    - RED = bit m+2 (MSB for that LED)
    - YELLOW = bit m+1 (middle bit)
    - BLUE = bit m (LSB for that LED)
    Example: value 3027 = 0b101110010011
    - LED 0 (leftmost): bits 11,10,9 = 101 → RED+YELLOW = ORANGE
    - LED 3 (rightmost): bits 2,1,0 = 011 → YELLOW+BLUE = GREEN
    [DisplayTask.cpp]
2025-11-09 Fix binary display mode initialization and make it the default
    - Changed boot logic: LOW = BINARY_DISPLAY (default), HIGH = VU_DISPLAY
    - Initialized display_mode in constructor to BINARY_DISPLAY
    - Added INPUT_PULLDOWN to DISPLAY_MODE_PUSHBUTTON_PIN to ensure LOW by default
    - Added Serial debug output to confirm which display mode is active at boot
    This ensures binary display mode works correctly and is the default mode.
    [DisplayTask.cpp]
2025-11-09 Fix display mode selection logic for external pull-up resistor
    - Changed pinMode from INPUT_PULLDOWN to INPUT (external pull-up exists)
    - Corrected boot logic: HIGH = BINARY_DISPLAY (default, not pressed)
    - Button pressed during boot (LOW) = VU_DISPLAY
    - Respects existing hardware pull-up configuration used by cycleDisplay()
    [DisplayTask.cpp]
2025-11-09 Fix binary display: revert LED ordering, show YELLOW for zero bits, remove debug
    - Reverted LED ordering: LED 0 (physical 8) shows LSB, LED 3 (physical 5) shows MSB
    - More LEDs lit = larger magnitude (intuitive)
    - Changed zero bits to display YELLOW instead of OFF
    - Removed Serial.println debug messages from run_boot()
    [DisplayTask.cpp]
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2025-11-09 Swap X and Y components in direction display due to IC orientation
    The IMU IC is physically installed with a rotated orientation on the PCB.
    To match the physical axes, X and Y components are swapped when displaying
    direction vectors in binary mode.
    [DisplayTask.cpp]
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2025-11-10 Fix binary magnitude display encoding: OFF for zero bits, GREEN for blue+yellow
    - Changed all-zero bits to display OFF instead of YELLOW
    - Fixed blue+yellow combination to show GREEN (0,255,0) instead of CYAN (0,255,255)
    This correctly implements the 3-bit encoding per LED where:
    - Bit 0 → Blue channel
    - Bit 1 → Yellow channel
    - Bit 2 → Red channel
    - All zero → OFF
    - Blue + Yellow → GREEN
    [DisplayTask.cpp]
2025-11-10 Fixed scaling issues for pressure & removed log for mag
    [globals.h]
2025-11-10 Add LSB masking for noisy IMU sensors to reduce display flicker
    Mask the 2 least significant bits for acceleration, magnetic field, and
    rotation velocity displays to reduce flickering caused by sensor noise.
    This quantizes values to multiples of 4, providing visual stability while
    maintaining full precision in SharedBuffer.
    Other sensors (temp, pressure, lux, volume) retain full 12-bit precision.
    [DisplayTask.cpp]
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2025-11-14 Align AS7331 implementation with other sensor patterns
    Refactored AS7331HAL to follow the same data flow pattern as other sensors:
    - AS7331HAL::read() now populates SensorData fields directly
    - SensorTask.cpp calls SharedBuffer::updateSpectralUVData() with sensorReading values
    - Removed SharedBuffer include from AS7331HAL.cpp (no longer needed)
    This matches the implementation pattern used by all other sensors (ICP201XX, BH1750, ICM20948, AS7343).
    [AS7331HAL.cpp, SensorTask.cpp]
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2025-12-12 Filter debug display to only show rates for initialized sensors
    Added isInitialized() method to sensor HAL interface to allow checking
    initialization status. Modified SensorTask debug output to only call
    printActualRate() for sensors that have been successfully initialized.
    This prevents displaying misleading rate information for optional sensors
    (AMG88XX, AS7343, AS7331) that may not be physically present.
    - Added virtual isInitialized() method to SensorHAL base class (returns true by default)
    - Overrode isInitialized() in AMG88XXHAL, AS7343HAL, and AS7331HAL to return their initialization status
    - Updated SensorTask::run_read() to check initialization before calling printActualR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
    [SensorHAL.h, SensorTask.cpp]
2025-12-12 Fix naming conflict between isInitialized member and method
    Renamed private member variable from 'isInitialized' to '_isInitialized'
    in AMG88XXHAL, AS7343HAL, and AS7331HAL to avoid naming conflict with
    the public isInitialized() method.
    This resolves compilation errors where the compiler couldn't distinguish
    between the member variable and the member function.
    [AS7331HAL.cpp, AS7343HAL.cpp]
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2026-07-05 Swapped INSERTED - LOW Logic for EDUV0
    [SDManager.cpp]
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2026-07-12 Fixed power draw bug when WiFi was unavailable
    [NetworkTask.cpp]
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
